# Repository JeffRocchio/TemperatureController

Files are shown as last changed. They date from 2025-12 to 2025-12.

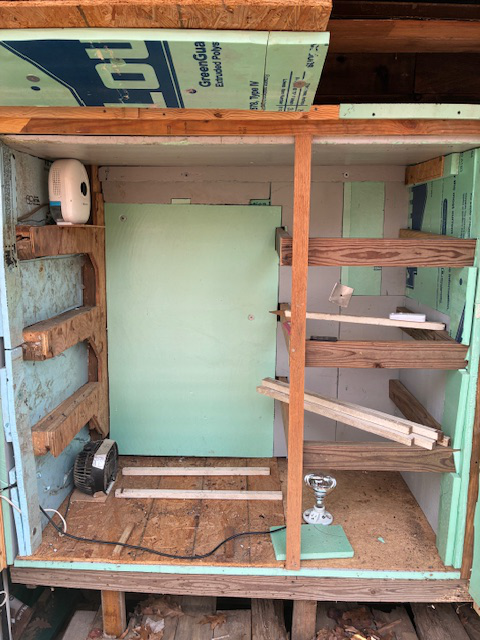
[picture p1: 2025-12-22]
hardware/wood-drying-box.jpg

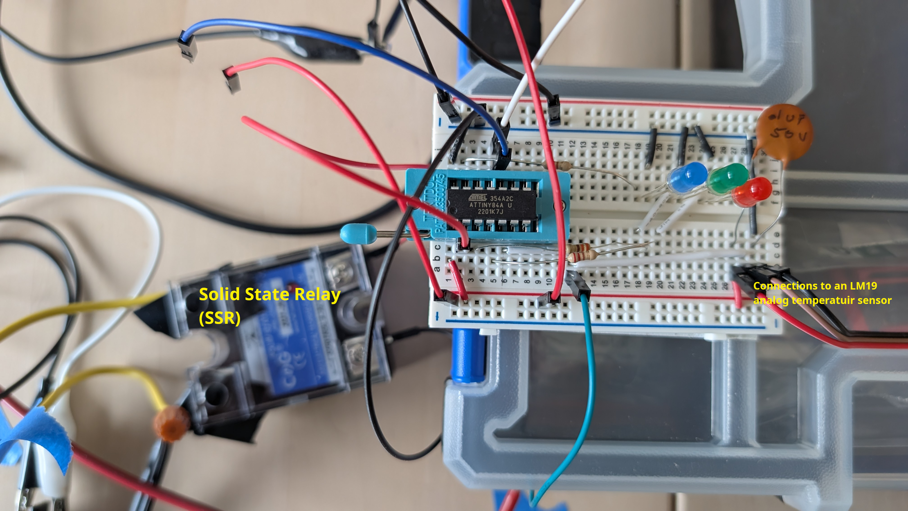
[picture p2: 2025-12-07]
hardware/POC_Breadboard.jpg

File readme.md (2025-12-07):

# Temperature Controller

## Purpose

A relatively simple controller that can be used for both a small wood dryer and a bread proofer. Suitable for cases where temperature can vary by 1-2 degrees from the set point and where up to about 500 watts of heating element power is sufficient. For my uses one to two incandescent lights bulbs will be the heating element. The limitation on heating element power draw is really just based on the SSR used, it's heat management, and sizing of the mains wiring. In my case I am using a SSR rated at 25 amps; but no heat sink, which is why I am limiting it to 500 watts. For my uses 1-2 incandescent lights bulbs will be the heating element.

## Physical Architecture

Device is based on an ATTiny 84a MCU chip and a Solid State Relay for controlling the heater element load.

The user sets the desired temperature by use of a potentiometer. There are three LEDs that provide very basic status information on the current temperature relative to the set-point.

## Software Architecture

Probably the only significant thing to note here is that the software is structured as a mini real-time-OS (RTOS). The main program loop calls the necessary 'tasks' continuously and with no hard-coded delays. Each task is assigned a time, in milliseconds, that defines the tempo at which it should actually execute. When the task is called (from the main loop) it checks to see if it is time for it to run itself. If not, it simply returns without running any of it's logic.

The other thing to be aware of is that this application does consist of multiple files. The status LEDs are managed by their own object class, which is contained in it's own .h and .cpp file. If the software is enhanced additional class may be developed and they will also be placed in their own class files.

## Status

As of December 6, 2025 I have the controller built on only a breadboard and am testing it's operation by using a cardboard box with the light bulb heat source under it.

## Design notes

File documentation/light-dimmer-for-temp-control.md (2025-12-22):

# Leo Wood Drying Thermostat Controller

Decided to use an ATTiny to control an SSR. So I have, in effect, turned most of the circuit design into software.

# References

### Using KiCad for Perf-Board Layout

See good article @ [https://forum.arduino.cc/t/perfboard-circuit-design-with-kicad/1283999](https://forum.arduino.cc/t/perfboard-circuit-design-with-kicad/1283999)

# For Reference - Other Circuit Ideas

## Light Dimmer with triacs, using 110v instead of 220v

https://forum.allaboutcircuits.com/threads/light-dimmer-with-triacs-using-110v-instead-of-220v.83001/

## Ideal, But More Complicated 

See figure 7 & figure 10 in: [Triac Principles and Circuits — Part 2](https://www.nutsvolts.com/magazine/article/triac_principles_and_circuits_part_2)

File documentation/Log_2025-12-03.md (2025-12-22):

# Dec 21, 2025

Started to put the electronics into a box for actual use. For the fun and learning of it I am using OnShape to work out the box dimensions and layout. I loved that I was able to create the digital logic components of the circuit in KiCad, using the PCB designer tool to layout those components on a perf-board, then export that perf-board as a 3D model, which I then imported into OnShape as a part for use in the physical box model. Nice.

For using KiCad to layout a perf-board see good article @ [https://forum.arduino.cc/t/perfboard-circuit-design-with-kicad/1283999](https://forum.arduino.cc/t/perfboard-circuit-design-with-kicad/1283999)

# Dec 6, 2025

Completed fully working prototype. Have it running to control temperature in a cardboard box on my work table upstairs. So far, so good.
# Dec 5, 2025

Using ChatGPT I created the first proof of concept of reading the temp sensor, comparing to a set-point that is based on a pot connected to an analog input pin, and turning the 'heater' device (i.e., output pin) on or off. See the sketch "TEST_ControlSetPoint."

Began creating what I hope to be the production sketch architecture. 
# Dec 4, 2025

I have the sketch 'POC_ButtonPress' working; and it does turn the SSR and attached light on/off as expected. 
# Dec 3, 2025

## Starting with a Fresh ATTiny Chip

I also started with a new install of the Arduino IDE as I had upgraded my PC to latest Fedora recently. So I downloaded the Arduino IDE appimage and then followed the instructions in the note "Arduino Setup for ATTiny Chips" that is in my general Notes repository and got the Blink sketch working.

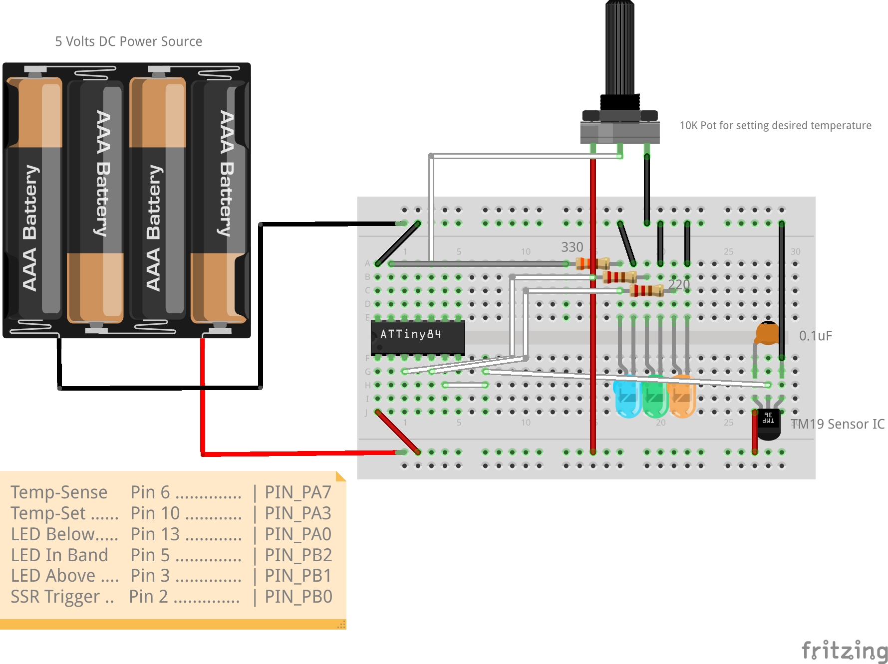
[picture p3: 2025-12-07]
hardware/Physical-Layout_Prototype.jpg

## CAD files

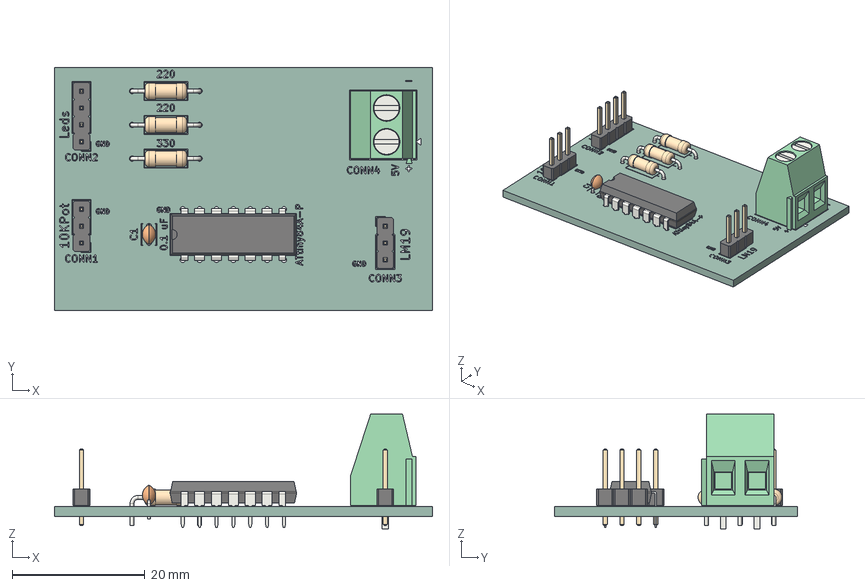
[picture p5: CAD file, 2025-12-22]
hardware/ATTiny-Carrier_3D-model.step
56.9 x 36.6 x 17.3 mm
PinHeader_1x03_P2.54mm_Vertical x 2
PinHeader_1x04_P2.54mm_Vertical
R_Axial_DIN0207_L6.3mm_D2.5mm_P10.16mm_Horizontal x 3
C_Disc_D3.0mm_W2.0mm_P2.50mm
DIP-14_W7.62mm
TerminalBlock_Phoenix_MKDS-1,5-2-5.08_1x02_P5.08mm_Horizontal
ATTiny-Carrier_silkscreen
ATTiny-Carrier_PCB

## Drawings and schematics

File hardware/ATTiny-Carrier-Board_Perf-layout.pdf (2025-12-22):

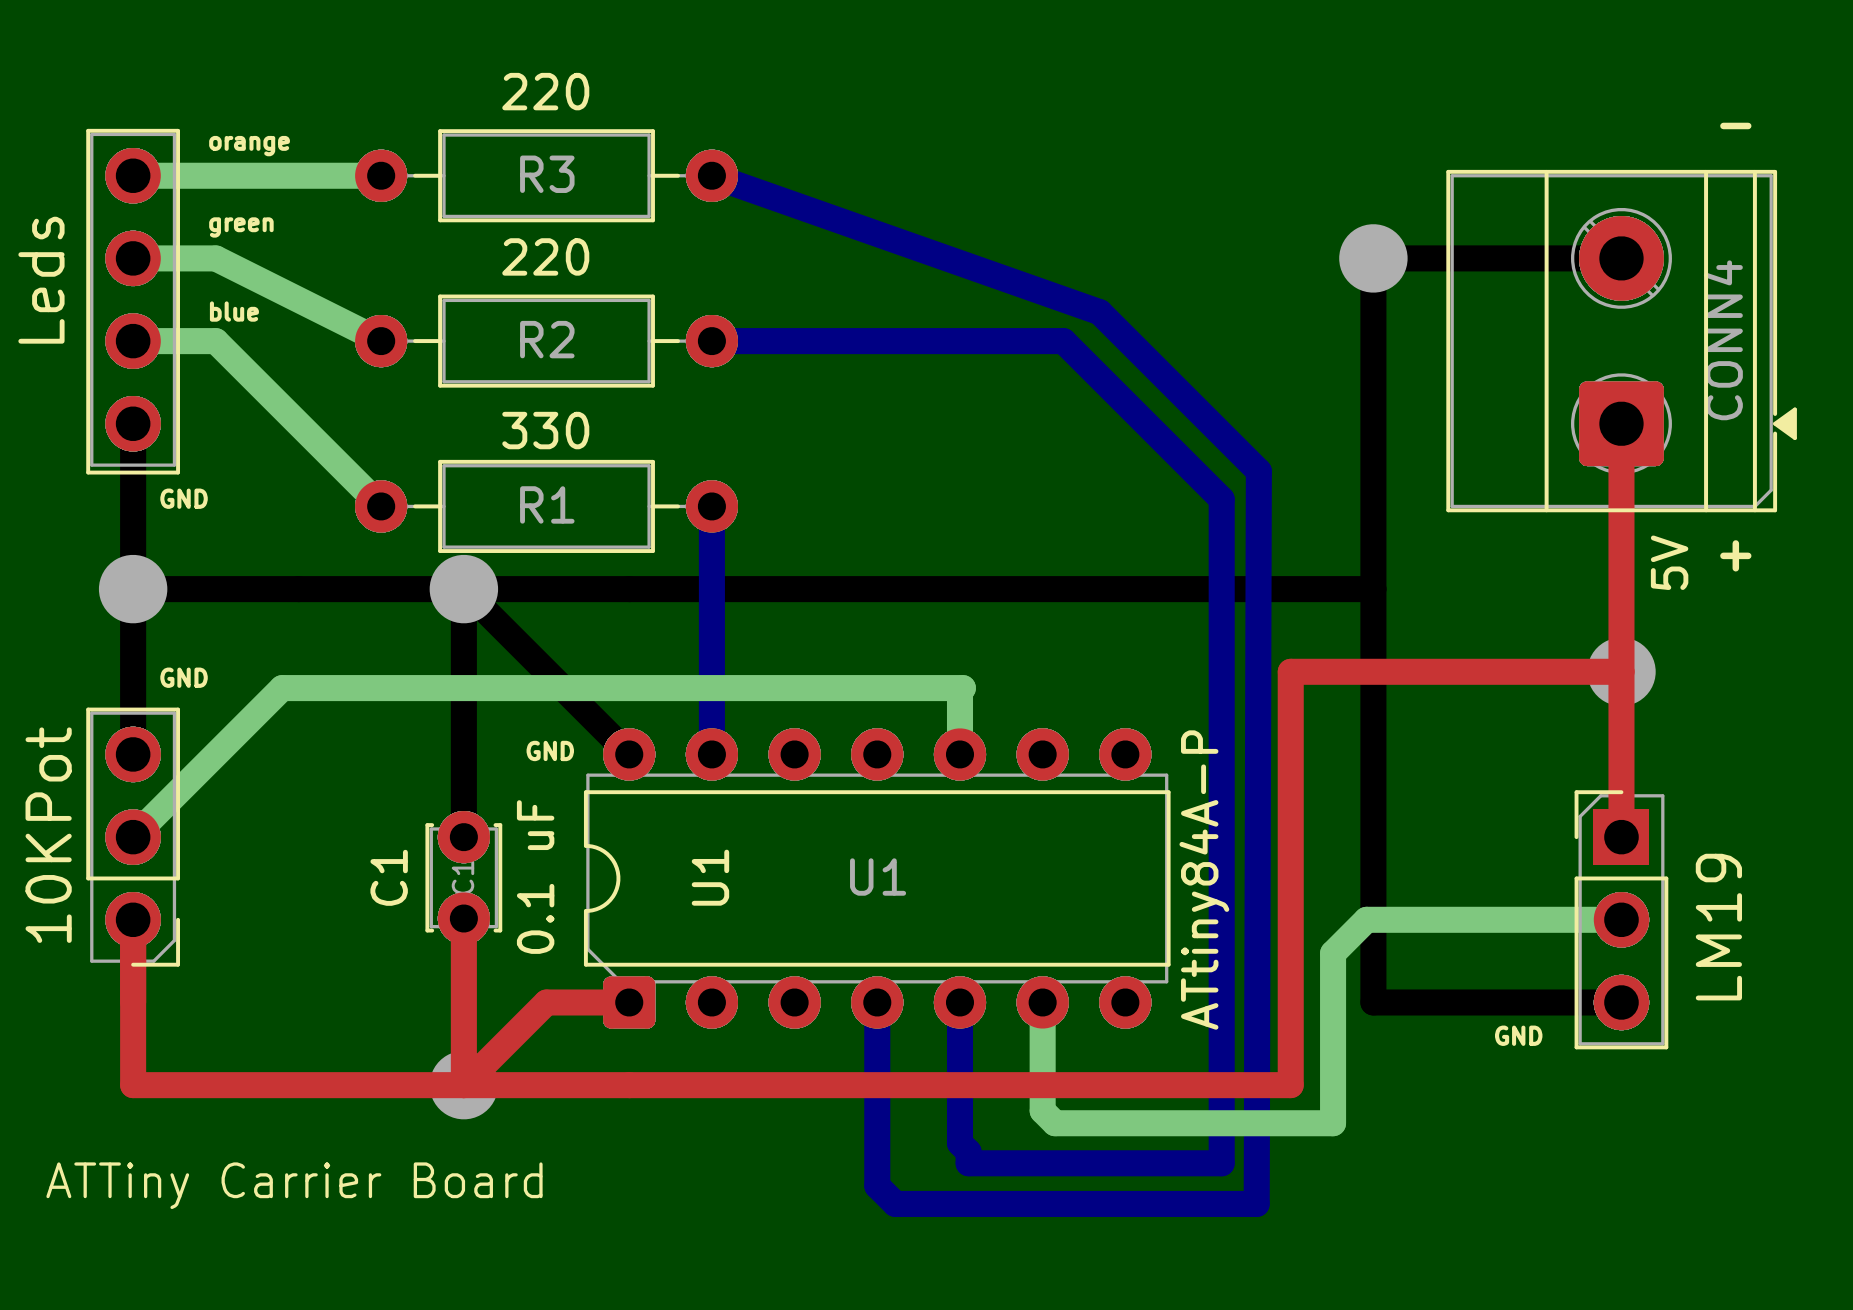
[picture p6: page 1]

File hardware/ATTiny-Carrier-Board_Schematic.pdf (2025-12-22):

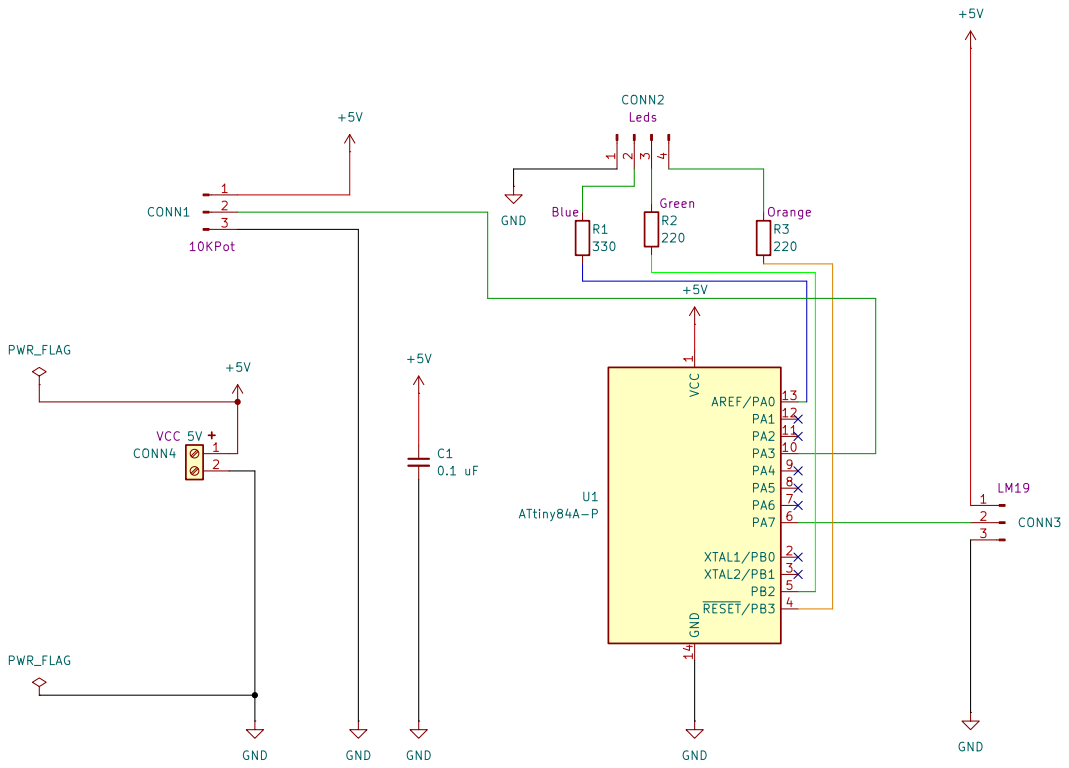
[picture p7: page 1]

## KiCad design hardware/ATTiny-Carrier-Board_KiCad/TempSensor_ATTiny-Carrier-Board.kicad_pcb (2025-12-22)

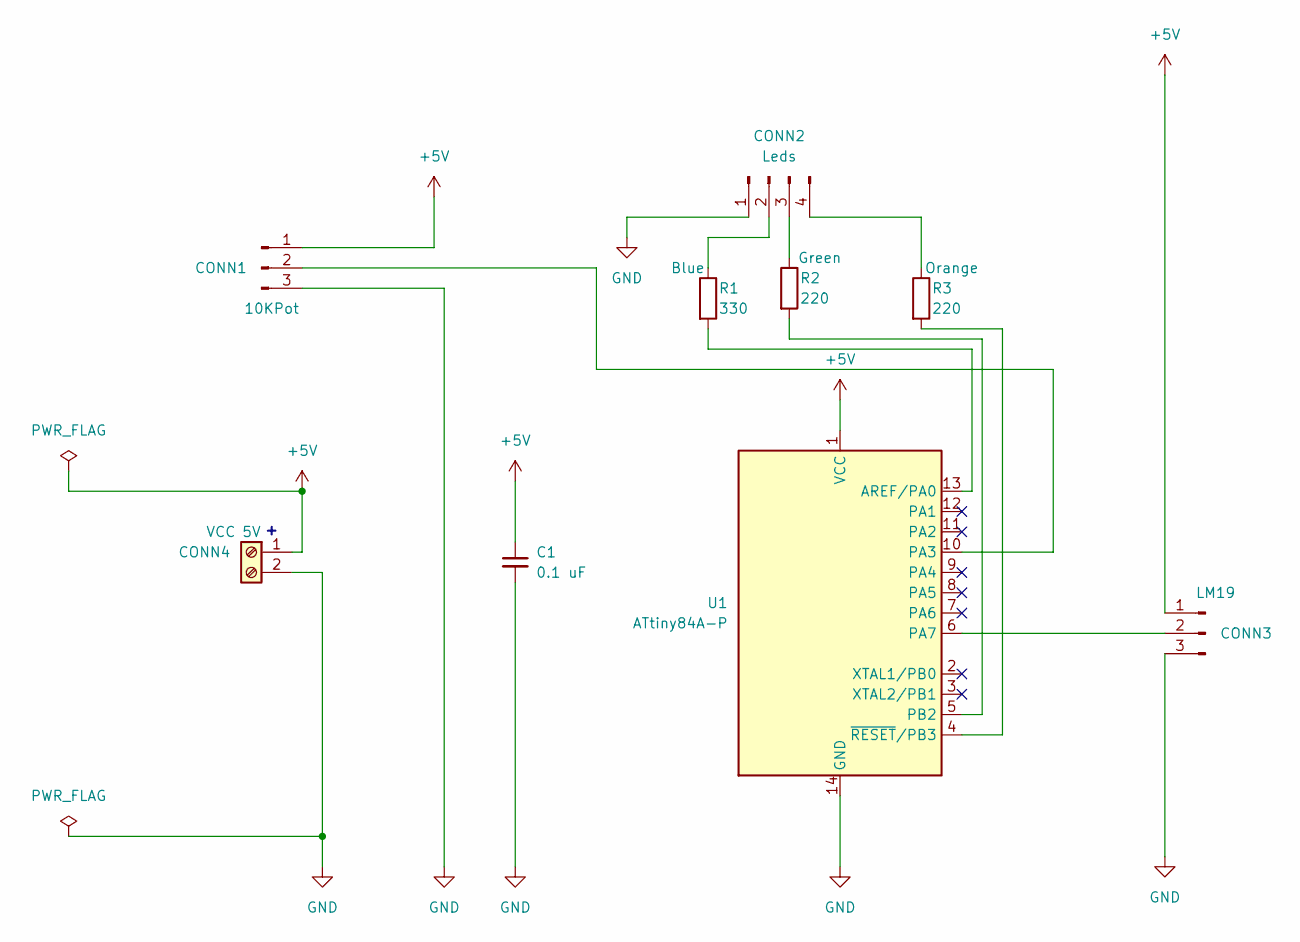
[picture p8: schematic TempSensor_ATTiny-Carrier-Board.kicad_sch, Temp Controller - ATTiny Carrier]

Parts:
C1: 0.1 uF; C_Disc_D3.0mm_W2.0mm_P2.50mm
CONN1, CONN3: Conn_01x03_Pin; PinHeader_1x03_P2.54mm_Vertical
CONN2: Conn_01x04_Pin; PinHeader_1x04_P2.54mm_Vertical
CONN4: 5V; TerminalBlock_Phoenix_MKDS-1,5-2-5.08_1x02_P5.08mm_Horizont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
R1: 330; R_Axial_DIN0207_L6.3mm_D2.5mm_P10.16mm_Horizontal
R2, R3: 220; R_Axial_DIN0207_L6.3mm_D2.5mm_P10.16mm_Horizontal
U1: ATtiny84A-P; DIP-14_W7.62mm

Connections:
+5V: C1.1, CONN1.1, CONN3.1, CONN4.1, U1.1 (VCC)
GND: C1.2, CONN1.3, CONN2.1, CONN3.3, CONN4.2, U1.14 (GND)
unnamed: CONN1.2, U1.10 (PA3)
unnamed: CONN2.2, R1.1
unnamed: CONN2.3, R2.1
unnamed: CONN2.4, R3.1
unnamed: CONN3.2, U1.6 (PA7)
unnamed: R1.2, U1.13 (AREF/PA0)
unnamed: R2.2, U1.5 (PB2)
unnamed: R3.2, U1.4 (~RESET/PB3)

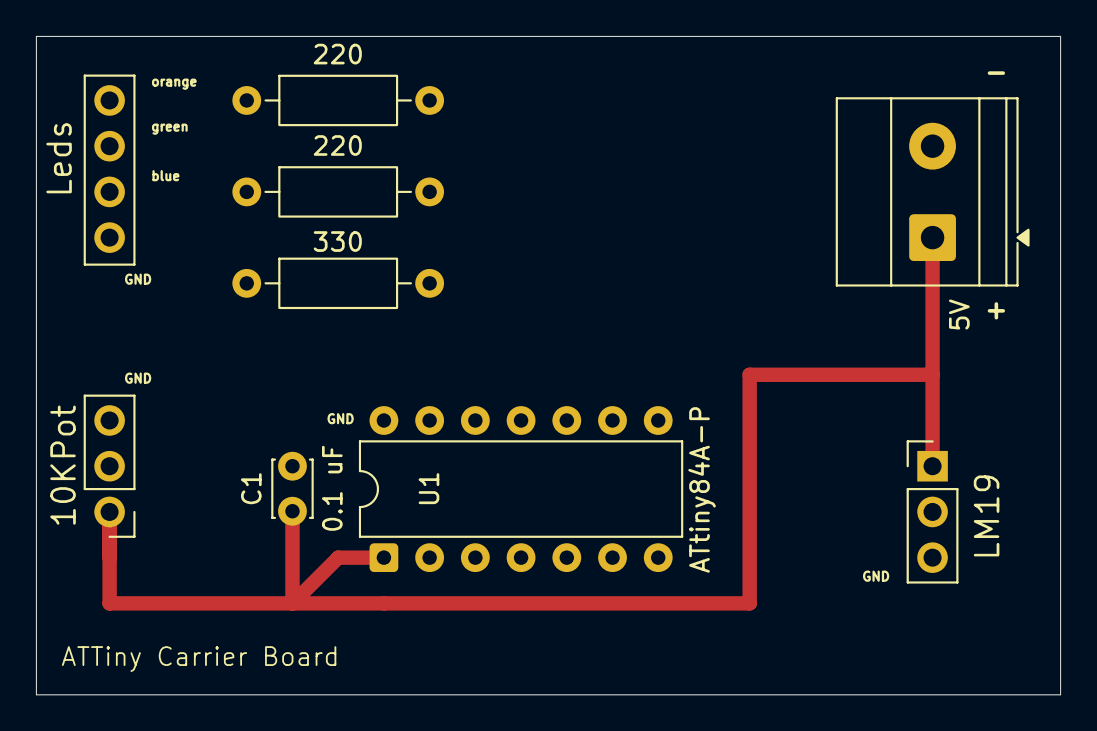
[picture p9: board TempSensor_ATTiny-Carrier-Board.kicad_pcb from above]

Board: 12 copper layers, 56.9 x 36.6 mm, 9 parts (0 on the bottom side), 10 nets.

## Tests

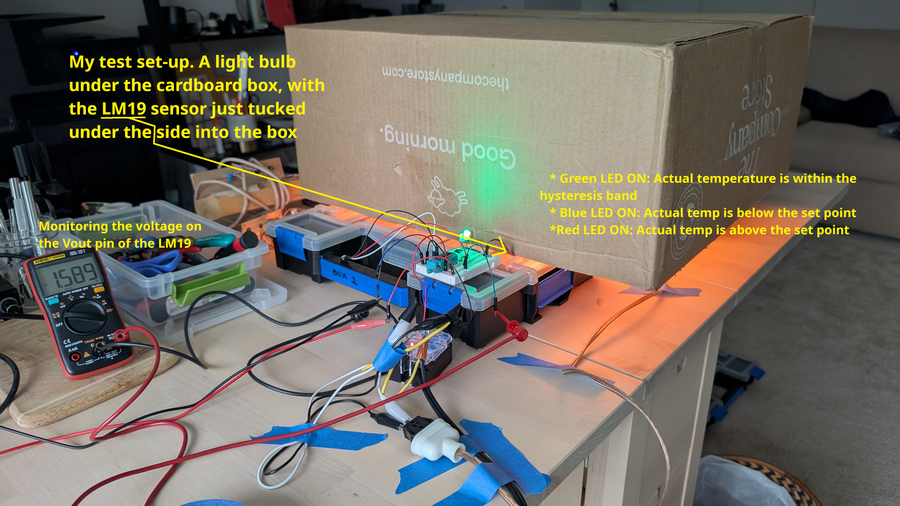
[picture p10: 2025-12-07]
hardware/POC_Test-set-up.jpg

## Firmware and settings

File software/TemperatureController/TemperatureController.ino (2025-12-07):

/*============================================================================
 DESCRIPTION: ATtiny84A Temperature Controller (Non-blocking Architecture)

 ASSUMPTIONS:
  * Heating element is 200 watts or less. Probably a light bulb or two.
  * We are using a solid-state relay (SSR) to control the heating element.
  * Temperature sensor is a TI-LM19 analog IC.
==============================================================================*/

/******************************************************************************
 CHANGE LOG:

 2025-12-06: initial creation (with help from ChatGPT).
*******************************************************************************/


//=============================================================================
//==== INCLUDES ===============================================================
#include "StatusLeds.h"

//=============================================================================
//==== INITIALIZATION SECTION =================================================
//     Define and initilize global variables (this section is for the compilier)

// ---------------- Digital Pin Assignments -----------------------------------
const uint8_t SSR_PIN         = PIN_PB0;  // physical pin  2 - SSR control (digital)
const uint8_t LED_ABOVE_PIN   = PIN_PB1;  // physical pin  3 - status LED
const uint8_t LED_INBAND_PIN  = PIN_PB2;  // physical pin  5 - status LED
const uint8_t LED_BELOW_PIN   = PIN_PA0;  // physical pin 13 - status LED

// ---------------- Analog Pin Assignments: using Ax form for ADC -------------
const uint8_t TEMP_PIN  = A7;       // PA7, physical pin 6 - LM19 Vout
const uint8_t POT_PIN   = A3;       // PA3, physical pin 10 - pot wiper

// ---------------- LM19 Constants --------------------------------------------
const float VREF        = 5.0;
const float LM19_V0C    = 1.8663;
const float LM19_SLOPE  = 0.01169;   // V/°C; T = (1.8663 - V)/0.01169

// ---------------- Setpoint Range --------------------------------------------
const float MIN_SET_F   = 50.0;      // bottom of pot
const float MAX_SET_F   = 90.0;      // top of pot
const float MID_SET_F   = 72.0;      // desired midpoint temperature

// ---------------- Control Tuning --------------------------------------------
const float HYST_F      = 2.0;       // hysteresis band (°F)
const float TEMP_ALPHA  = 0.1;       // EMA factor for filtered temp

// ---------------- Task Intervals --------------------------------------------
const unsigned long TEMP_SAMPLE_MS    =  250; // how often to sample LM19
const unsigned long CONTROL_UPDATE_MS = 1000; // how often to update heater
const unsigned long LED_UPDATE_MS     =  200; // how often to update the status LEDs

// ---------------- Global State ----------------------------------------------
float filteredTempF      = 72.0;     // start, or seed it, near room temp
bool  heaterOn           = false;    // current heater state
bool  inDeadband         = false;    // true if temp is between ON/OFF thresholds
float setPointF          = 72.0;     // Making set-point global

// ---------------- Timing State ----------------------------------------------
unsigned long lastTempSampleMs  = 0;
unsigned long lastControlMs     = 0;
unsigned long lastLedBlinkMs    = 0;
bool          ledBlinkState     = false;

// ---------------- Declare Objects -------------------------------------------
StatusLeds statusLeds(
  LED_ABOVE_PIN,
  LED_INBAND_PIN,
  LED_BELOW_PIN,
  HYST_F,
  LED_UPDATE_MS
);


//=============================================================================
//==== SET-UP SECTION =========================================================
//     This runs once at ATTiny boot-up. Configure the ATTiny.

void setup() {
  pinMode(SSR_PIN, OUTPUT);
  digitalWrite(SSR_PIN, LOW);

  analogReference(DEFAULT); // Vcc as ADC reference

  statusLeds.begin();       // Using StatusLeds object, configure chip to use it
  statusLeds.selfTest();    // Show user all LEDs are working
}

//=============================================================================
//==== APPLICATION MAIN LOOP ==================================================

void loop() {
  unsigned long now = millis();

  taskSampleTemperature(now);
  taskUpdateControl(now);
  statusLeds.setDisplayState(filteredTempF, setPointF);
  statusLeds.updateLEDs(now);
}


//=============================================================================
//==== FUNCTIONS ==============================================================

/******************************************************************************
 PURPOSE: Read LM19 and return °C

 NOTES: 
  - We take an average from multiple readings of the sensor in order to
    minimize noise. 
  - We are also guarding against extreme edge cases by testing for, and 
    setting, min/max possible values.
  - The formula: tC = (LM19_V0C - v) / LM19_SLOPE is what converts the 
    read ADC value read from the LM19, at the ATTiny pin it is connected to,
    into a temperature value. This formula was derived by ChatGPT from the
    LM19 datasheet, which contains a temperature to Vout table and graph.
    ChatGPT also claims that the values for V0C and the Slope are values that
    are commonly seen in application notes and example code across the
    internet.
*******************************************************************************/
float readTemperatureC() {
  const uint8_t N_SAMPLES = 8;
  uint32_t sum = 0;

  for (uint8_t i = 0; i < N_SAMPLES; i++) {
    sum += analogRead(TEMP_PIN);
  }

  float raw = sum / (float)N_SAMPLES;
  float v = (raw * VREF) / 1023.0;

  // Clamp to sane LM19 range
  if (v < 0.2) v = 0.2;
  if (v > 2.8) v = 2.8;

  float tC = (LM19_V0C - v) / LM19_SLOPE;
  return tC;
}

// Celsius → Fahrenheit
float readTemperatureFOnce() {
  float c = readTemperatureC();
  return c * 9.0 / 5.0 + 32.0;
}

/******************************************************************************
 PURPOSE: Read the position of the potentiometer and use that to establish
  the user's desired temperature set-point.

 NOTES:
  - Global constants are used to establish the range of temperatures the pot
    can span; as well as the temperature set-point that we want the midpoint
    of the pot to represent.
  - We are doing some work here to make sure the pot positions are responsive
    to our desired range and midpoint.
*******************************************************************************/
float readSetpointF() {
  uint16_t rawADC = analogRead(POT_PIN);
  float raw = rawADC;             // convert ADC to float for math to follow

  const float MID_RAW = 511.5f;   // center of the 0–1023 value ADC pins return

  if (raw <= MID_RAW) {
    // Values: [0 .. MID_RAW] map to range: [MIN_SET_F .. MID_SET_F]
    float spanRaw  = MID_RAW - 0.0f;          // ≈ 511.5
    float spanTemp = MID_SET_F - MIN_SET_F;   // ex: 72 - 50 = 22°F
    float frac = (spanRaw > 0.0f) ? (raw / spanRaw) : 0.0f;
    return MIN_SET_F + spanTemp * frac;
  } else {
    // Values: [MID_RAW .. 1023] map to range: [MID_SET_F .. MAX_SET_F]
    float spanRaw  = 1023.0f - MID_RAW;       // ≈ 511.5
    float spanTemp = MAX_SET_F - MID_SET_F;   // ex: 90 - 72 = 18°F
    float frac = (spanRaw > 0.0f) ? ((raw - MID_RAW) / spanRaw) : 0.0f;
    setPointF = MID_SET_F + spanTemp * frac;  // setPointF is a global state variable
    return setPointF;
  }
}

/******************************************************************************
 PURPOSE: Sample temperature periodically and update filteredTempF

 NOTES:
  - filteredTempF: This variable represents the actual temperature measured by 
    the LM19 after being run through an exponential moving average (EMA) to 
    remove jitter and stabilize the control loop. It is dynamic. 
    It changes continuously as the room or enclosure changes temperature.
  - Our mini-RTS: We continuously call this funtion in the main loop; but it
    only actually execute at a tempo that is given by the sampling rate
    (in milliseconds) that we have set in the global constant for that.
*******************************************************************************/
void taskSampleTemperature(unsigned long now) {
  if (now - lastTempSampleMs < TEMP_SAMPLE_MS) {
    return;
  }
  lastTempSampleMs = now;

  float tempFraw = readTemperatureFOnce();

  // Exponential moving average
  filteredTempF = filteredTempF * (1.0f - TEMP_ALPHA) + tempFraw * TEMP_ALPHA;
}

/******************************************************************************
 PURPOSE: Update heater control based on filtered temp + setpoint

 NOTES:
  - Our mini-RTS: We continuously call this funtion in the main loop; but it
    only actually execute at a tempo that is given by the sampling rate
    (in milliseconds) that we have set in the global constant for that.
  - The hysteresis band is the full swing between low and high. So the idea is
    that the set-point is the middle of that band. E.g., if HYST_F = 2.0, and
    the set-point is 70-degrees, then the temp will vary between 69-71.
*******************************************************************************/
void taskUpdateControl(unsigned long now) {
  if (now - lastControlMs < CONTROL_UPDATE_MS) {
    return;
  }
  lastControlMs = now;

  float setF = readSetpointF();
  float tempF = filteredTempF;
  const float halfBand = HYST_F * 0.5f;

  bool wantOn = heaterOn;  // default: keep current state
  inDeadband = false;

  if (tempF <= setF - halfBand) {
    // Too cold: turn heater on
    wantOn = true;
  } else if (tempF >= setF + halfBand) {
    // Too hot: turn heater off
    wantOn = false;
  } else {
    // Between thresholds: deadband
    inDeadband = true;
  }

  heaterOn = wantOn;

  // Drive SSR immediately when state changes
  digitalWrite(SSR_PIN, heaterOn ? HIGH : LOW);
}

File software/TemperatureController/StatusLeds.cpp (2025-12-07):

#include "StatusLeds.h"

/******************************************************************************
 DESCRIPTION: Constructor, using initializer list.
*******************************************************************************/
StatusLeds::StatusLeds(
        uint8_t abovePin,
        uint8_t inBandPin,
        uint8_t belowPin,
        float hysteresisF,
        unsigned long updateIntervalMs)
      :
      _abovePin(abovePin),
      _inBandPin(inBandPin),
      _belowPin(belowPin),
      _hysteresisF(hysteresisF),
      _updateIntervalMs(updateIntervalMs),
      _lastUpdate(0),
      _region(AtSetPoint),
      _lastRegion(AtSetPoint)
      {}


/******************************************************************************
 DESCRIPTION: Call this before using any other methods of this object.
  This configures the chip for use of this object.
*******************************************************************************/
void StatusLeds::begin() {
    pinMode(_abovePin, OUTPUT);
    pinMode(_inBandPin,  OUTPUT);
    pinMode(_belowPin,   OUTPUT);

    digitalWrite(_abovePin, LOW);
    digitalWrite(_inBandPin,  LOW);
    digitalWrite(_belowPin,   LOW);
}

/******************************************************************************
 DESCRIPTION: Based on the current state of the actual temperature and the 
  set-point this method will determine which LEDs should be lit in order to
  inform the user.

 NOTES: 
  - This method determines the state, but does not actually affect the LEDs'
    On/Off state. I am keeping that in a seperate method in order to have
    flexibility. E.g., future revisions may want to incorporate some add'l 
    status or whatnot. It may also be the case that future iterations may
    make more complex use of the LEDs such that having where they get turned
    On/Off be seperate will better enable that.
  - Given the above note, remember that it is important to call the 
    updateLEDs() function in the main program loop (or in some function that
    gets called during each loop iteration).
  - The behavior of the LEDs is: If we are right at the Set Point then only
    green LED is on. If we are within the hysteresis band, but above the set
    point then both the orange and green LED is on. If in band and below, then
    both the green and blue LED is on. If outside of the band then the blue or
    orange LED is on, respectively; but green is off.
*******************************************************************************/
void StatusLeds::setDisplayState(float tempF, float setPointF) {
  const float halfBand = _hysteresisF * 0.5f;

  if (tempF < setPointF - halfBand) {
    _region = Below;
  } else if ((tempF >= setPointF - halfBand) && (tempF <= setPointF)) {
    _region = InBandBelow;
  } else if ((tempF <= setPointF + halfBand) && (tempF >= setPointF)) {
    _region = InBandAbove;
  } else if (tempF > setPointF + halfBand) {
    _region = Above;
  } else {
    _region = AtSetPoint;
  }
}

/******************************************************************************
 DESCRIPTION: Based on the current state of _region make sure the correct 
  status LED is lit.

 NOTES:
  - The method setDisplayState() must be called periodically in order to set
    the state of _region.
  - This is intended to be a non-blocking function that gets called as part of
    the RTS structure in the application's main loop() function.
*******************************************************************************/
void StatusLeds::updateLEDs(unsigned long now) {
  if (now - _lastUpdate < _updateIntervalMs) {
    return;
  }
  _lastUpdate = now;

  if (_region == _lastRegion) return; // No status change, nothing to do

  _lastRegion = _region;

  bool belowOn    = false;
  bool inBandOn   = false;
  bool aboveOn    = false;

  switch (_region) {
    case Below:
      belowOn = true;   // below lower bound of band
      break;
    case InBandBelow:
      inBandOn = true;  // in hysteresis band
      belowOn = true;   // and below the setpoint
      break;
    case AtSetPoint:
      inBandOn = true;  // right at the set point
      break;
    case InBandAbove:
      inBandOn = true;  // in hysteresis band
      aboveOn = true;   // and above the setpoint
      break;
    case Above:
      aboveOn = true;   // above upper bound of setpoint
      break;
  }

  digitalWrite(_abovePin, aboveOn ? HIGH : LOW);
  digitalWrite(_inBandPin,  inBandOn  ? HIGH : LOW);
  digitalWrite(_belowPin,   belowOn   ? HIGH : LOW);
}



/******************************************************************************
 DESCRIPTION: Self test. Use at boot-up to show that all LEDs are working.
*******************************************************************************/
void StatusLeds::selfTest() {
  uint8_t pins[3] = { _belowPin, _inBandPin, _abovePin };

  // Step each LED
  for (uint8_t i = 0; i < 3; i++) {
    digitalWrite(pins[i], HIGH);
    delay(250);
    digitalWrite(pins[i], LOW);
  }
  // All on
  digitalWrite(_abovePin, HIGH);
  digitalWrite(_inBandPin, HIGH);
  digitalWrite(_belowPin, HIGH);
  delay(250);
  // All off
  digitalWrite(_abovePin, LOW);
  digitalWrite(_inBandPin, LOW);
  digitalWrite(_belowPin, LOW);
  delay(250);
  // Step each LED
  for (uint8_t i = 0; i < 3; i++) {
    digitalWrite(pins[i], HIGH);
    delay(250);
    digitalWrite(pins[i], LOW);
  }
}


/******************************************************************************
 DESCRIPTION: Turn all LEDs off.
*******************************************************************************/
void StatusLeds::allOff() {
  digitalWrite(_abovePin, LOW);
  digitalWrite(_inBandPin, LOW);
  digitalWrite(_belowPin, LOW);
}

/******************************************************************************
 DESCRIPTION: Getter methods
*******************************************************************************/
StatusLeds::Region StatusLeds::region() const { 
  return _region; 
}

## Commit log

2025-12-07 Initializing git with first completed proof-of-concept
    [Physical-Layout_Portotype.fzz]
2025-12-22 Working breadboard prototype
    [ATTiny-Carrier_3D-model.step, Physical-Layout_Portotype.fzz, Physical-Layout_Prototype.fzz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]
